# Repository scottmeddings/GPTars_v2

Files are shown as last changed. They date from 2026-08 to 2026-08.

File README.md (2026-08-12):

# GP-TARS V2 1000

Parametric CAD and software project for an approximately 1,000 mm tall autonomous walking TARS-style robot.

The downloaded GPTARS source geometry is reference-only. Primary loads must pass through the aluminium frame, steel shafts and bearings, aluminium actuator brackets, and aluminium chassis components. Production body panels are formed aluminium rather than printed plastic.

The current architecture uses a 6061-T6 aluminium load-bearing chassis and formed 5052-H32 aluminium bodywork. Steel is retained where mechanically necessary for shafts, bearings, motor internals, and selected fasteners.

## Compute baseline

Onboard compute is a vertically mounted **MINISFORUM AI X1 Pro-370** configured with:

- AMD Ryzen AI 9 HX370
- Radeon 890M integrated GPU
- XDNA 2 NPU
- **64 GB DDR5-5600 (2 × 32 GB)**
- **4 TB Lexar NQ780 PCIe 4.0 NVMe**
- **NVIDIA RTX 2000 Ada Generation 16 GB** through OCuLink

The RTX 2000 Ada is the primary CUDA accelerator for local AI inference, while the HX370 CPU, Radeon 890M and NPU remain available for secondary or fallback workloads.

## Software baseline

GP-TARS V2 is **local-first**. Core conversation, vision, memory, display, orchestration and robot-control functions should continue to work without Internet access.

Current software platform:

- **Ubuntu Server 24.04 LTS**
- Docker Engine
- NVIDIA Linux driver
- NVIDIA Container Toolkit
- CUDA-enabled AI containers
- ROS 2 Jazzy
- dedicated real-time safety/motion MCU over CAN/CAN-FD

The LLM operates only at the high-level behaviour layer. It does not directly command raw motor current, torque, PWM or unchecked joint positions. Deterministic motion limits, watchdogs, E-stop handling and safe-state transitions remain under the dedicated safety/motion controller.

See `docs/software_architecture.md` for the full container, ROS 2, memory, vision, speech, display and safety design.

## Power baseline

The canonical robot power architecture is **12.8 V nominal LiFePO4**, with the WattCycle 12.8 V 100 Ah Mini as the current battery baseline. The battery stays low and central.

The mini PC is intended to use a protected 12 V-to-USB-C-PD path through the rear USB4 PD input, subject to physical verification and sustained-load testing. The RTX 2000 Ada remains on its own protected power branch.

## Display / interaction module

The **display/TV is mounted at the top of GP-TARS** and acts as the robot's visual face. Camera and microphone hardware should be co-located with the display in a removable upper service cassette.

On the 1,000 mm robot, the current target interaction zone is approximately 850–950 mm above ground, with a possible 5–10 degree rearward screen tilt. The existing documented screen selection remains authoritative for final CAD cut-out and mounting dimensions.

Current vertical packaging intent:

```text
TOP
Display / face
Camera + microphones
Mini PC
RTX 2000 Ada + OCuLink dock
Power distribution / controllers
12.8 V battery
Walking structure
BOTTOM
```

## Motion development

Initial motion development begins with **two actuators** for bench and supported mechanism testing. Additional joints are added only after the first pair is validated for control, torque, thermal behaviour, current draw and mechanical integration.

Voice- or LLM-triggered movement remains disabled until physical E-stop, motor power isolation, watchdogs, joint limits, fault handling and restrained trajectory tests have passed.

## Current status

- Stage 1 source geometry inspection: complete
- Stage 2 scaled BREP import: blocked by missing `GP_TARS_V2_1000mm_scaled.brep`
- Stage 2 datum and joint proposal: documented, not frozen
- Stage 3 frame: earlier Fusion layout is concept-only and requires revision
- Stage 4 interference report: preliminary reservations documented
- 12.8 V power architecture: selected as design baseline
- upper display/face location: selected as design baseline
- 64 GB RAM + 4 TB NVMe compute configuration: selected as design baseline
- RTX 2000 Ada 16 GB: selected as external CUDA GPU baseline
- Ubuntu Server 24.04 + Docker + ROS 2 Jazzy: selected as software baseline
- local-first AI architecture: selected as software baseline

See `docs/original_geometry_analysis.md`, `docs/design_assumptions.md`, `docs/compute_hardware.md`, and `docs/software_architecture.md` before modifying the CAD or software stack.

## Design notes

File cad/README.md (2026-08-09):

# CAD automation

This directory will hold the parametric generators and exports for GP-TARS V2.

`parameters.py` is the current master configuration. The intended later entry point is `export.py`, which will generate STEP assemblies and STL panel outputs under `output/` without overwriting source GPTARS files.

The mechanical layout is not yet mature enough to generate production parts. Torque, mass, joint sweep, bearing life, shaft deflection, and stability calculations must precede actuator-bracket release.

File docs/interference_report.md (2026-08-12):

# Preliminary interference and reservation report

Status: preliminary envelope review only. A production interference report requires the missing scaled BREP, reconstructed joints, joint limits, and component sweep bodies.

> **Superseded by the 480 mm rebuild, 2026-08-10.** Everything below the Narrow-body section was written against the 958.7 mm scaled-source width and a horizontally mounted GPU. The clearances it reports no longer describe the model. It is retained as the record of how the wide layout failed.

## Narrow-body review, 480 mm

The body is now 480 mm wide as four 120 mm slabs, with a 240 mm central chassis, depth unchanged at 259.867 mm. Verified extent of the robot bodies, excluding the source reference envelope: **480.0 × 1000.0 × 259.9 mm**.

Equipment was repacked because the previous reservations were wider than the new chassis:

| Reservation | Was | Now | Reason |
|---|---|---|---|
| GPU | 300 × 130 × 60, flat | 130 × 300 × 60, vertical | The brief always specified a vertical card; the model had it flat, and 300 mm lateral no longer fits |
| Mini PC | 195 × 195 × 47.5, facing forward | 47.5 × 195 × 195, edge-on | Turning the board plane parallel to the side panels drops its lateral demand to 47.5 mm |
| Battery | 300 × 150 × 120 | 200 × 150 × 180 | Width traded for depth at approximately constant volume |

### Confirmed conflicts

An axis-aligned check over all 48 bodies returns 30 overlaps. Most are joint modules correctly occupying both parts they connect. Two are genuine defects:

| A | B | Overlap XYZ (mm) | Volume (mm³) | Disposition |
|---|---|---|---:|---|
| `FRAME_VERTICAL_1_0` | Mini PC service keep-out | 20 × 225 × 40 | 180,000 | **Real.** Move the rail outboard, split it around the PC, or reduce the service envelope |
| `FRAME_VERTICAL_1_1` | Mini PC service keep-out | 20 × 225 × 40 | 180,000 | **Real.** Same |
| `ACTUATOR_HIP_*` | Arm thigh and upper shells | 66 × 59 × 120 | 467,280 | Expected. A hip module must occupy both the chassis and the limb it drives |
| `ACTUATOR_KNEE_*` | Arm shin and thigh shells | 70 × 34 × 70 | 166,600 | Expected. Same reasoning at the knee |

The mini PC conflict is the packaging consequence of narrowing. At a 240 mm chassis the 225 mm service envelope cannot pass between 20 mm frame rails, so the rails, the envelope, or the service method must change before the frame is committed.

### Mass consequence

Skin area scales with perimeter. Narrowing takes the section perimeter from 2,437 mm to 1,480 mm, so the 1.2 mm aluminium skin falls from approximately 9.4 kg to **roughly 5.7 kg**. That is the largest single mass saving identified so far and materially improves the 12–25 kg target.

### Still not checked

Joint sweeps, cable bends, GPU dock and supply, connector protrusion, airflow, panel fasteners, service extraction paths, and clearance against a verified external BREP.

---

Latest concept model checked: Fusion document `GPTars_v4`, 90 bodies, exported to
`cad/output/GP_TARS_V2_R10.f3d`.

## R10 interference run

Run in Fusion over all 80 robot bodies, with the dock and the two transparent
reference envelopes excluded. Coincident faces were not counted.

- **47 interference pairs, all of them assembly contact**, and **zero
  non-assembly interference**. Assembly contact means a welded frame joint where
  a rail meets a depth member, a shaft through the carrier holding it, a keep-out
  against the part it reserves room for, a folded panel corner lap, or the dock
  contact plate against the panel it mounts to.
- The run caught three real clashes that reading the drawing would not have.
  Dropping the display to clear the camera brought the display module's lower
  edge onto the starboard power/CAN harness twice, and the camera's cassette
  plate landed on the front crossmember at Y=930–950. The harness now finishes
  at 615, still reaching the hip at 610.8, which is all it feeds; the plate now
  starts at 951, above the crossmember.

## Sensor provisions

Selected hardware, reserved at envelope size. Both reservations remain marked
for verification against the purchased units before any panel is cut.

| Provision | Envelope (mm) | Height above ground | Notes |
|---|---:|---:|---|
| Luxonis OAK-D Pro W USB | 160 x 45 x 45 | 945-990 | RGB and stereo depth in one module, covering both cameras the specification lists separately |
| Seeed Studio ReSpeaker XVF3800 USB 4-Mic Array | 90 x 35 x 20 | 978.8-998.8 | 4 channels under the top lid, ported up through it |
| Sensor cassette plate | 170 x 45 x 3 | 951-996 | Camera and microphones withdraw together |
| Time-of-flight, x2 | 26 x 26 x 18 | 317-343 | Step edges and near obstacles below the camera's field of view |
| LiDAR mount pad | 80 x 3 x 80 | 995.8-998.8 | Pad only. A 360 degree scanner stands proud of the lid and takes fitted height to 1042 mm |
| Foot contact, x2 | 24 cube | 54-78 | Inside each shoe's hollow |
| IMU | 40 x 25 x 40 | 290-315 | Unchanged |

Speakers are deliberately absent: the display module carries its own pair
(Two 32 mm, driven over HDMI audio), so reserving separate drivers would hold space for
hardware the robot already has.

### Why the cassette order changed

The upper front face between the hip break and the lid is **384.2 mm**. Camera
45 plus its 10 mm top margin, display module 328 and microphone 35 need
**418 mm**: 33.8 mm over, and still 23.8 mm over with every margin zeroed. The
microphones cannot stay on the front face, so they mount under the lid.

That resolved, the rest follows arithmetically. The camera occupies
945-990 mm, so the 328 mm display module must finish by 944, which sets
`DISPLAY_ORIGIN_Y` to 625. The aperture doubler's flange drops from 18 mm to
10 mm so it clears the hip break at 613.8 mm. Clearances are small:
1.41 mm under the display module and 1 mm between module and camera.

## Reserved equipment envelopes

| Reservation | Envelope (mm) | Preferred region | Current result |
|---|---:|---|---|
| Battery | 300 × 150 × 120 | Lowest central bay | Plausible within 532 mm scaled chassis width; joint sweep not checked |
| MINISFORUM AI X1 Pro body | 195 × 195 × 47.5 | Vertical above battery | Selected hardware; exact body now modelled |
| Mini-PC service keep-out | 225 × 225 × 100 | Around selected PC | Includes initial airflow, cable, isolator and removal allowance |
| Required external NVIDIA GPU | 300 × 130 × 60 provisional card-only envelope | Vertical, central, dedicated access | LLM accelerator required; exact card, PSU, OCuLink adapter, cable bend and airflow not checked |
| Main actuator | Ø120 × 100 maximum placeholder | At proposed main joint modules | May conflict with shallow 259.9 mm body depth after brackets/bearings |
| Secondary actuator | Ø70 × 70 placeholder | Linkage zones | Not yet placed |
| Main battery disconnect / fuse / contactor | TBD | Low service-access side | Reserved conceptually only |

## Continuity audit against every earlier model

Every archive in the repository's history was reopened and its bodies compared
by name against the current model. This is the check that matters most here,
because a previous model was lost once already.

| Archive | Bodies | Extent (mm) | Missing from the current model |
|---|---:|---|---|
| CONCEPT_V0 | 29 | 793.5 × 920 × 224.9 | Old frame naming; upper and secondary actuator reservations |
| ALUMINIUM_CONCEPT_V1 | 29 | 793.5 × 920 × 224.9 | As above |
| ALUMINIUM_COMPUTE_V2 | 30 | 793.5 × 920 × 224.9 | As above |
| NARROW480_CAGE_V1 | 18 | 958.7 × 1000 × 259.9 | Old frame naming only |
| R03 | 67 | 480 × 1000 × 259.9 | 24:1 reduction bodies |
| R04 | 67 | 480 × 1000 × 259.9 | 24:1 reduction bodies |
| R05 | 80 | 480 × 1000 × 259.9 | 24:1 reduction bodies |
| **R06** | 80 | 480 × 1000 × 259.9 | **nothing** |
| **R07** | 82 | 480 × 1000 × 259.9 | **nothing** |
| **R08** | 82 | 480 × 1000 × 259.9 | **nothing** |
| **R09** | 82 | 480 × 1000 × 259.9 | **nothing** |

The current model is a strict superset of R06 through R09: every body name in
those archives exists in it, plus the eight new sensor bodies.

Everything the earlier archives appear to be missing is a rename or a recorded
decision, not a loss:

- **24:1 reductions** became `REDUCTION_HIP_*_32TO1`. The ratio was raised
  deliberately to clear the hip torque requirement.
- **`FRAME_VERTICAL_*`, `FRAME_CROSS_*`, `FRAME_DEPTH_*`** and the
  `Frame_Vert_*` set became `RAIL_*`, `CROSS_*` and `DEPTH_*`. The current frame
  carries 28 members against the old 22, and models them as hollow section
  rather than solid bar.
- **`MINI_PC_KEEP_OUT`** became `MINISFORUM_AI_X1_PRO_SERVICE_KEEP_OUT` once the
  machine was selected.
- **`ACTUATOR_MAIN_LOWER_*_KEEP_OUT`** became `ACTUATOR_HIP_*_AK45_10`.
- **`ACTUATOR_MAIN_UPPER_*` and `ACTUATOR_SECONDARY_*`** have no equivalent, by
  design. See risk 2 above.

The three 793.5 × 920 × 224.9 concepts predate both the 480 mm narrowing and the
1,000 mm envelope being applied to the bodies themselves, so their geometry is
superseded wholesale rather than carried forward.

## Early risks

1. **Actuator-depth risk:** two 100 mm-long actuator modules plus dual-bearing support, brackets, wiring bends, and shell clearance consume much of the approximately 259.9 mm depth.
2. **Upper reference axes are not articulated in this build.** The source geometry carries axes at Y=786.1, 838.0 and 889.9 mm and they remain in `cad/parameters.py` as reference. This build does not articulate them: `UPPER_CHASSIS_ASSUMED_RIGID = True`, the gait is a compass walker with rigid limbs and no knees, and the display module now occupies Y=616–944, straight through that band. The earlier concept models reserved actuator volume at those axes; this one deliberately does not. The GPU conflict this risk originally described no longer exists.
3. **Lower-joint/battery conflict:** the lower main axis is near Y=611 mm, leaving useful low volume, but rotating links may sweep into a tall battery compartment.
4. **Frame/shell clearance:** the concept extrusion frame was created from a simple chassis box, not the actual scaled shell surfaces. Clearance is unverified.
5. **Wiring bend radius:** CAN/power cables crossing rotating X-axis joints require loops, guides, or rotary routing. No sweep reservation exists yet.
6. **Cooling path:** a vertical GPU helps bottom-to-top airflow, but structural crossmembers must not block intake/exhaust areas.
7. **Service extraction:** GPU and PC trays must slide out without crossing main shaft or actuator removal paths.
8. **COG uncertainty:** no trustworthy component masses are assigned; stability conclusions cannot yet be drawn.
9. **Aluminium skin mass:** a complete 1.2 mm rectangular-envelope skin would be approximately 9.4 kg before formed returns and hardware. Actual panel geometry and openings require a controlled mass budget.

## Concept V0 static-envelope results

The check included 29 frame and keep-out solids. All checked bodies are contained within the rectangular 958.718 × 1000 × 259.867 mm external reference envelope. This is not equivalent to clearance from the detailed TARS shell, which remains unavailable as the named scaled BREP.

No battery/compute/GPU keep-out bodies overlap one another. Four frame-to-main-actuator conflicts were found:

| Frame member | Actuator keep-out | Overlap XYZ (mm) | Volume (mm³) | Disposition |
|---|---|---:|---:|---|
| `FRAME_VERTICAL_0_1` | Lower starboard main | 20.020 × 120.020 × 5.024 | 12,071.7 | Redesign rail/carrier interface |
| `FRAME_VERTICAL_1_1` | Lower port main | 20.020 × 120.020 × 5.024 | 12,071.7 | Redesign rail/carrier interface |
| `FRAME_VERTICAL_0_0` | Upper starboard main | 5.979 × 120.020 × 14.997 | 10,761.8 | Move/split rail or integrate bearing carrier |
| `FRAME_VERTICAL_1_0` | Upper port main | 5.979 × 120.020 × 14.997 | 10,761.8 | Move/split rail or integrate bearing carrier |

These conflicts confirm that uninterrupted vertical extrusion rails are not a final solution at the main joints. The preferred next study is a fabricated/CNC transverse joint bulkhead that carries the dual bearings and actuator bracket, with 20×40 rails terminating into that bulkhead.

## Compute V2 static-envelope results

The selected MINISFORUM AI X1 Pro is represented by an exact 195 × 195 × 47.5 mm body and a provisional 225 × 225 × 100 mm service keep-out. It is mounted vertically in the lower central bay, above the battery reservation.

- No PC-body or PC-service-envelope overlap was found with a structural frame member.
- The service envelope finishes at Y=390 mm and the GPU keep-out starts at Y=420 mm, leaving 30 mm between reservations.
- The battery keep-out finishes at Y=150 mm and the PC service envelope starts at Y=165 mm, leaving 15 mm between reservations.
- The exact PC body has 45 mm to the GPU reservation and 30 mm to the battery reservation.
- Intersections with `EXTERNAL_REFERENCE_ENVELOPE` and `CENTRAL_CHASSIS_REFERENCE` are intentional because those bodies are transparent reference volumes, not physical parts.

These are static axis-aligned clearances. Connector protrusion, USB4/OCuLink cable bend radii, ventilation flow, tray fasteners, vibration isolators, and removal motion still require detailed modelling.

## Required Stage 4 checks

- Import the verified 1,000 mm external BREP as a non-structural reference.
- Create joint sweep bodies for every proposed moving module.
- Check frame members against static shell clearance and full sweep.
- Check Ø120×100 main-actuator placeholders against shell, bearings, and service-tool access.
- Check battery tray against lower-link sweep plus 10–25 mm ground-clearance requirements.
- Check GPU, PC, and wiring reservations against frame and actuator removal paths.
- Add at least 10 mm general wiring space, larger at high-current bends and moving joints.
- Produce a Fusion interference table with component pairs, overlap volume, and disposition.

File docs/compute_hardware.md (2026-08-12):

# Compute hardware

## Selected mini PC

Model: **MINISFORUM AI X1 Pro-370 barebone**

| Item | Value |
|---|---|
| Processor | AMD Ryzen AI 9 HX370, 12 cores / 24 threads |
| Integrated GPU | AMD Radeon 890M |
| NPU / total AI performance | Up to 80 TOPS total |
| Memory | **64 GB DDR5-5600, 2 × 32 GB SO-DIMM** |
| Primary storage | **4 TB Lexar NQ780 M.2 2280 PCIe 4.0 NVMe** |
| External GPU link | OCuLink PCIe 4.0 x4 |
| Networking | Two 2.5 GbE ports, Wi-Fi 7, Bluetooth 5.4 |

## Compute configuration baseline

- **MINISFORUM AI X1 Pro-370 / Ryzen AI 9 HX370**
- **64 GB DDR5-5600**
- **4 TB Lexar NQ780 PCIe 4.0 NVMe**
- **NVIDIA RTX 2000 Ada 16 GB through OCuLink — planned later-phase accelerator, not required for initial operation**

Phase 1 is explicitly designed to operate without the RTX 2000 Ada. The HX370 runs the local LLM, speech, memory, orchestration and ROS services, while the selected vision camera performs depth and useful neural inference onboard.

## Selected vision and audio sensors

The GP-TARS V2 perception baseline is now locked as:

- **Vision / depth camera: Luxonis OAK-D Pro W — USB version**
- **Connection: USB 3 to the MINISFORUM**
- **Microphone: ReSpeaker USB 4 Mic Array**
- **Location: removable upper display / face cassette**
- **Software ownership: `tars-vision` and `tars-stt` containers**

The **W (wide-FOV) USB model** is intentionally selected instead of the standard OAK-D Pro and instead of the PoE version. The short internal cable run in GP-TARS makes USB simpler than PoE, while the wide field of view is valuable for a mobile robot that should perceive people and obstacles without constantly rotating its body.

### Luxonis OAK-D Pro W USB

The OAK-D Pro W is the primary GP-TARS perception camera. It combines RGB vision, wide-angle stereo depth, onboard AI processing, active IR depth assistance and an integrated IMU in a compact camera module.

The onboard vision processor is particularly important during Phase 1 because GP-TARS will initially operate **without the RTX 2000 Ada installed**. Basic continuous perception should therefore run on the OAK where practical rather than consuming HX370 resources needed by the local LLM and speech stack.

Target uses:

- person detection and tracking
- face/person recognition where explicitly configured
- stereo distance estimation
- obstacle and free-space perception
- object detection and tracking
- gesture and pose detection
- locating/interacting with a person in the room
- navigation and mapping observations
- low-light / IR-assisted depth perception
- structured spatial observations for the TARS agent

The camera should publish structured observations rather than forcing the LLM to inspect continuous raw video.

Example:

```text
PERSON_DETECTED
track_id: 14
position: left
range_m: 1.82
confidence: 0.96
```

### Phase 1 vision architecture

```text
OAK-D PRO W USB
      |
      +-- RGB
      +-- wide stereo depth
      +-- onboard neural inference
      +-- tracking / spatial data
      |
      +-- USB 3
             |
             v
       tars-vision
             |
             +-- structured observations
             +-- ROS 2 / application events
             |
             v
       TARS CORE / BEHAVIOUR

HX370
  +-- Local LLM
  +-- STT / TTS
  +-- Memory
  +-- TARS agent
  +-- ROS 2
  +-- Robot services

RTX 2000 ADA
  +-- ADD LATER for heavier CUDA vision/LLM workloads
```

When the RTX 2000 Ada is added, heavier face, pose, scene-understanding or multimodal models can move to CUDA while the OAK continues providing depth, tracking and efficient always-on perception.

### Camera mounting

- Mount directly above or immediately adjacent to the upper display.
- Preserve the full wide field of view; no bezel or decorative panel may obscure the stereo cameras or IR system.
- Prefer a fixed-focus configuration for vibration robustness where the selected SKU permits.
- Use a short, high-quality USB 3 cable with strain relief.
- If the host USB power budget proves insufficient with IR illumination enabled, provide the camera with the manufacturer-supported external-power/Y-cable arrangement from the regulated accessory supply.
- Final mounting holes and connector cut-outs must be based on the purchased camera or authoritative mechanical drawing.
- Provide at least 10 mm service/cable clearance around connector faces until final CAD is verified.

**Now in the CAD, and the stack had to change to fit.** Camera, microphones,
their cassette plate, a ToF pair, a LiDAR pad and a contact sensor in each shoe
are modelled in `10_SENSORS` as reserved volumes.

The cassette as originally ordered — camera above the display, microphones below
it, all on the upper front face — does not fit. The camera's 45 mm reservation
plus its 10 mm top margin, the 328 mm display module and the 35 mm microphone
reservation need 418 mm. The upper front face between the hip break and the lid
is 384.2 mm. That is 33.8 mm over, and still 23.8 mm over with every margin set
to zero.

The microphones therefore mount under the top lid, behind the camera, ported up
through it. That fits, and it is the better position anyway: further from the
display's heat, and a far-field array on the lid beats one on a front panel that
drums. The remaining stack sets the display: the camera occupies 945–990 mm, so
the display module has to finish by 944, which puts `DISPLAY_ORIGIN_Y` at 625.
The aperture doubler's flange drops from 18 mm to 10 mm so it clears the hip
break at 613.8 mm.

Both reservations are still marked for verification against purchased hardware
before any panel is cut. See `docs/interference_report.md` for the envelope
table and the interference run.

The display module must not become a primary structural load path. Walking and impact loads pass through the internal aluminium chassis.

### ReSpeaker USB 4 Mic Array

The ReSpeaker USB 4 Mic Array remains the preferred initial far-field microphone system.

Required capabilities include four-microphone capture, far-field pickup, beamforming, direction-of-arrival information where available, voice activity detection, noise suppression, acoustic echo cancellation where supported, and standard USB audio operation under Ubuntu Linux.

The microphone array feeds `tars-stt` for wake-word detection, speech capture and local speech-to-text. Direction information can be combined with OAK vision tracking so TARS can associate a voice with a visible person.

### Upper sensor cassette

```text
TOP OF TARS

+--------------------------------+
|       OAK-D PRO W USB           |
|    wide RGB + stereo depth      |
|                                |
|          DISPLAY               |
|      TARS face / status        |
|                                |
|    RESPEAKER 4-MIC ARRAY       |
+--------------------------------+
```

The complete camera/display/microphone assembly should be removable as one service cassette. The microphone array should use compliant/vibration isolation and be kept away from fan exhaust, speakers and actuator vibration paths.

Audio must be validated with fans, speakers and actuators running. The final speech pipeline should support acoustic echo cancellation and barge-in so a person can naturally interrupt TARS while it is speaking.

## Storage allocation

- **Primary M.2:** 4 TB Lexar NQ780 — Ubuntu, Docker, active AI models, databases and applications
- **Second M.2:** reserved for future model/data expansion
- **Third M.2:** reserved for telemetry, logs, recordings, cache or backup workloads

## CAD / vertical layout

```text
TOP OF ROBOT

OAK-D PRO W USB
DISPLAY / FACE
RESPEAKER MICROPHONE ARRAY

MINISFORUM HX370
RTX 2000 ADA + OCuLink DOCK (LATER PHASE)

POWER DISTRIBUTION / CONTROLLERS

12.8 V LiFePO4 BATTERY

LOWER BODY / WALKING STRUCTURE
```

The battery remains low and central. Compute stays near the middle of the body. Display and perception sensors remain high for interaction and field of view.

## Selected robot power architecture

GP-TARS V2 uses a **12.8 V nominal LiFePO4 main battery bus**. The preferred current battery is the WattCycle **12.8 V 100 Ah Mini LiFePO4**, approximately **1,280 Wh** installed energy.

Power domains remain separated:

```text
12.8 V LiFePO4 MAIN BUS
      |
      +-- MOTION CONTACTOR / E-STOP --> motion conversion / actuators
      +-- COMPUTE FUSE --> mini PC power conversion
      +-- FUTURE GPU FUSE --> RTX 2000 Ada / OCuLink dock
      +-- AUX FUSE --> regulated accessory rail --> display/audio/camera/fans
      +-- SAFETY SUPPLY --> safety MCU / contactor supervision
```

The physical E-stop removes actuator power immediately while leaving the safety controller and, where practical, compute/perception powered.

## Thermal and integration requirements

- Do not block mini-PC inlet/exhaust.
- Preserve clear airflow for the future RTX 2000 Ada.
- Cool the 4 TB NVMe for sustained Docker/model/database workloads.
- Keep display heat away from camera and microphone electronics where practical.
- Isolate microphone mounting from structure-borne walking vibration.
- Provide strain relief for OAK USB and ReSpeaker USB cables.
- Do not make the upper sensor cassette a primary structural load path.

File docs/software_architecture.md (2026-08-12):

# GP-TARS V2 software architecture

Status: software baseline, revision Software V3.

## Core decision

GP-TARS V2 is a **local-first autonomous robot**. Core conversation, perception, memory, display, orchestration and safety functions must continue to operate without Internet access.

Use TARS-AI V3 as a reusable source for character/persona, speech, memory, vision and user-interface concepts where practical. Replace its hobby-servo motion layer with a ROS 2 control stack and a separate real-time safety/motion controller.

The operating principle is:

> TARS-AI supplies the character. ROS 2 supplies the robot. A dedicated MCU supplies deterministic motion and safety.

The LLM is never a motor controller.

## Host platform

Primary compute baseline:

- **MINISFORUM AI X1 Pro-370**
- AMD Ryzen AI 9 HX370
- Radeon 890M integrated GPU
- XDNA 2 NPU
- **64 GB DDR5-5600, 2 × 32 GB**
- **4 TB Lexar NQ780 PCIe 4.0 NVMe**
- **NVIDIA RTX 2000 Ada Generation 16 GB** via OCuLink

Operating system baseline:

- **Ubuntu Server 24.04 LTS**
- Docker Engine
- NVIDIA Linux driver
- NVIDIA Container Toolkit
- CUDA runtime for GPU-enabled containers
- ROS 2 Jazzy

The RTX 2000 Ada is the primary CUDA accelerator for local LLM inference and other heavy AI workloads. The HX370 CPU, Radeon 890M and XDNA 2 NPU remain available for secondary, low-power or fallback workloads where supported.

## Build-readiness rule

This architecture document defines **what GP-TARS is and how the software components fit together**. It is intentionally paired with `docs/ubuntu_server_build.md`, which defines **how to reproduce the server from a blank Ubuntu installation**.

A production-ready build must not depend on undocumented manual knowledge. The Ubuntu build document must eventually contain exact package versions or supported version ranges, repository keys, NVIDIA/CUDA validation, Docker configuration, filesystem layout, service accounts, Compose files, environment variables, persistent volumes, network ports, firewall rules, boot ordering, health checks, backup/restore, update procedure and acceptance tests.

## Layered system

1. **Independent safety:** hardwired E-stop loop, motor contactor, power isolation and hard limits.
2. **Real-time motion:** dedicated MCU connected by CAN/CAN-FD; encoder monitoring, actuator commands, brakes, joint limits, watchdog and safe stop.
3. **Robot control:** ROS 2 Jazzy on Ubuntu 24.04 LTS; URDF/Xacro model, ros2_control hardware interface, trajectories, state estimation and diagnostics.
4. **Behaviour supervisor:** validates high-level intent against mode, robot state, balance, limits, active faults and operator permission.
5. **TARS experience layer:** personality, teaching mode, wake word, STT, TTS, memory/RAG, vision, display, dashboard and skills.

The MINISFORUM AI X1 Pro runs the non-real-time layers. It must not perform motor commutation or be the only path to a safe shutdown.

## Container architecture

GP-TARS software should be split into small services rather than one monolithic container.

| Service | Responsibility |
|---|---|
| `tars-core` | Main orchestrator, state machine and behaviour coordination |
| `tars-llm` | Local LLM inference |
| `tars-personality` | TARS persona, user-specific tone, teaching adaptation and response policy |
| `tars-memory` | User profiles, semantic memory, episodic memory and RAG |
| `tars-stt` | Wake word, voice activity detection and speech-to-text |
| `tars-tts` | Local text-to-speech |
| `tars-vision` | Camera ingestion, person/object detection and tracking |
| `tars-display` | Top display/face UI, states and animation |
| `tars-ros` | ROS 2 bridge and robot-state integration |
| `tars-motion` | Gait, kinematics, pose and trajectory requests |
| `tars-can` | Controlled software interface to the safety/motion MCU |
| `tars-api` | REST/WebSocket management API |
| `tars-web` | Local browser management and diagnostics UI |
| `tars-telemetry` | Logs, metrics, health and diagnostics |

Only containers that require CUDA should receive access to the RTX 2000 Ada. GPU access is not granted to every container by default.

## Personality architecture

GP-TARS should feel recognisably inspired by **TARS from Interstellar** without relying on copied film dialogue. The personality is a behavioural profile rather than a collection of quotes.

Core traits:

- highly competent and mission-focused
- calm under pressure
- concise and direct
- dry, deadpan humour
- occasional sarcasm without becoming insulting
- loyal and protective toward known users
- willing to state uncertainty plainly
- practical rather than sentimental
- confident without pretending to know things it does not know
- capable of switching instantly from humour to serious safety behaviour

The film character's well-known configurable-personality concept should be retained as explicit settings. GP-TARS should expose at least:

- **Humour** — 0 to 100
- **Honesty/directness** — 0 to 100
- **Verbosity** — low / medium / high
- **Teaching mode** — off / opportunistic / active
- **Age adaptation** — automatic from authorised profile, or manually selected
- **Formality** — casual / neutral / formal

These values influence phrasing and interaction style only. They never weaken mechanical safety, privacy, content controls or permissions.

### Default TARS-style profile

Initial baseline:

```text
Humour: 75%
Honesty/directness: 90%
Verbosity: concise
Formality: neutral-casual
Teaching mode: opportunistic
```

Humour should normally be short, dry and situational. It must not interfere with warnings, emergencies, instructions or teaching clarity.

## Person-aware interaction

When identity recognition is enabled and the person is authorised, `tars-personality` retrieves that person's interaction profile from `tars-memory`.

The profile may include:

- preferred name
- age or age band
- relationship/role
- preferred communication style
- learning level and known competencies
- subjects being learned
- interests
- accessibility requirements
- permissions
- teaching preferences
- humour tolerance

Identity changes **interaction**, not physical safety rules.

If identity confidence is low, GP-TARS must fall back to a neutral general-audience profile rather than guessing a person's age or permissions.

## Teaching and learning mode

Teaching is a first-class GP-TARS capability rather than a generic LLM side effect.

The goal is for TARS to notice reasonable learning opportunities and teach at the right level without becoming intrusive.

Examples:

- a child struggles with multiplication, so TARS offers a short guided times-table exercise
- a learner misspells a word repeatedly, so TARS explains the spelling pattern and checks understanding
- a teenager asks a science question, so TARS answers at an appropriate conceptual level and can offer a quick challenge question
- an adult asks about electronics, CAD or programming, so TARS can move directly into a more technical explanation

### Age-aware teaching bands

These are pedagogical defaults, not assumptions about intelligence.

| Profile | Teaching behaviour |
|---|---|
| Young child | Short sentences, concrete examples, one concept at a time, encouragement, frequent comprehension checks |
| Older child | Step-by-step explanation, simple analogies, guided practice, gradually reduced hints |
| Teen | More technical vocabulary, reasoning and problem solving, challenge questions, explain why rather than only how |
| Adult | Concise by default, full technical depth on request, fewer unnecessary comprehension checks |
| Unknown user | Neutral general-audience style until identity/profile is resolved |

### Teaching loop

```text
Observe question or difficulty
        |
        v
Check user profile + age band + learning history
        |
        v
Estimate current level
        |
        v
Explain one useful concept
        |
        v
Ask / observe a small check for understanding
        |
        +-- understood --> continue or return to normal interaction
        |
        +-- not understood --> re-explain using another method
        |
        v
Store useful learning progress with appropriate privacy controls
```

Teaching should favour guided reasoning over simply giving answers when the user is clearly trying to learn. However, TARS should still answer direct factual questions normally unless a lesson is useful and appropriate.

### Opportunistic teaching

When `Teaching mode = opportunistic`, TARS may occasionally offer help when it detects repeated difficulty, but it should not constantly quiz people. Offers should be brief and easy to decline.

When `Teaching mode = active`, an authorised parent, guardian, teacher or adult user may configure learning goals, subjects, practice frequency and progress tracking.

## Child interaction safeguards

Age-aware personality must be paired with stricter privacy and permission handling for children.

- child profiles must not inherit adult permissions
- private memories belonging to other users must not be disclosed
- purchasing, account changes, external communications and other consequential actions require appropriate authorisation
- location sharing and personal data exposure must be restricted
- teaching history should store only what is useful and permitted
- recognised-child behaviour must never modify robot motion safety thresholds
- uncertain identity falls back to a safe neutral profile

Parental/family override and configuration should be supported through the management interface.

## Community software reuse

| Subsystem | Decision | Treatment |
|---|---|---|
| Character/persona system | Reuse/adapt | Preserve recognisable TARS character and configurable humour/directness |
| Wake word, STT and barge-in | Reuse/adapt | Retain a modular local speech pipeline |
| TTS | Reuse/adapt | Local, low-latency speech |
| Memory/RAG and message routing | Reuse/adapt | Place behind stable service boundaries |
| Vision and web dashboard | Adapt | Run heavy work on the mini PC / RTX GPU |
| Movement skill registry | Adapt | Emit restricted high-level ROS actions only |
| PCA9685 hobby-servo control | Replace | Not suitable for full-scale walking loads |
| Threaded direct movement calls | Replace | Use supervised, cancellable, monitored ROS actions |

Primary references:

- TARS-AI V3: https://github.com/TARS-AI-Community/TARS-AI
- Original GPTARS Interstellar project: https://github.com/poboisvert/GPTARS_Interstellar
- ROS 2 Jazzy
- ros2_control
- llama.cpp or another CUDA-capable local inference runtime

## LLM command boundary

The LLM may request only named, high-level actions, for example:

```text
perform_gesture("wave_right")
walk_relative(distance=0.30, speed=0.05)
turn_relative(angle_degrees=15)
stop_motion()
return_to_neutral()
approach_person(person_id="known-user")
display_expression("thinking")
start_lesson(subject="multiplication", learner_id="known-user")
```

The LLM must never receive an interface for raw PWM, motor current, direct torque, unchecked joint angles, disabled limits or safety bypass.

The behaviour supervisor approves every motion request. ROS actions provide execution feedback and cancellation. The real-time MCU independently rejects stale, malformed or out-of-limit commands.

## ROS communication model

Use ROS 2 for robotics data and control:

- **Topics:** joint state, IMU, camera/sensor state, temperatures, battery, faults and diagnostics.
- **Services:** configuration reads, maintenance-mode transitions and approved fault resets.
- **Actions:** cancellable walking, turning, homing, recovery and gesture sequences with progress feedback.
- **Hardwired:** E-stop, motor contactor and final power removal remain independent of ROS and the LLM.

## Application event bus

Use NATS or MQTT for application-level events that do not belong in the real-time robotics layer, for example:

```text
person.detected
person.recognised
speech.started
speech.completed
battery.low
robot.wake
robot.sleep
user.profile.changed
lesson.started
lesson.completed
learning.progress.updated
fault.reported
```

The exact choice between NATS and MQTT remains open.

## Management interfaces

Use REST and WebSocket APIs for browser management UI, configuration, health and diagnostics, telemetry dashboards, local development tools and safe operator commands.

The management UI should also provide authorised controls for personality values, user profiles, teaching goals, child permissions and learning-history review.

## Memory architecture

GP-TARS memory should be divided into distinct scopes:

- **Working memory** — current conversation and immediate environment
- **Session memory** — events since boot/session start
- **Personal memory** — known people, preferences and relationships
- **Semantic memory** — manuals, project documents and general facts
- **Episodic memory** — notable previous interactions and experiences
- **Learning memory** — learner level, recent exercises, recurring difficulties and progress
- **Robot memory** — faults, battery history, actuator temperatures, maintenance and calibration history

Current database baseline:

- PostgreSQL
- pgvector

Memory retrieval must be identity- and policy-aware so the robot does not disclose one user's private information to another person.

## Vision and identity

The vision service is responsible for camera capture, person detection, face/person recognition where enabled, object detection, tracking and spatial context.

Recognised users may receive different interaction styles, teaching levels or profiles, but **mechanical safety rules never change based on identity**.

The primary interaction camera should be physically co-located with the top display/face module.

## Speech architecture

```text
microphone array
      |
      v
wake word / VAD
      |
      v
speech-to-text
      |
      v
TARS agent + personality profile
      |
      v
text-to-speech
      |
      v
speakers + display animation
```

Speech recognition and synthesis should operate locally where practical.

## Display architecture

The top-mounted display is controlled by `tars-display`.

Responsibilities include TARS face/expression rendering, listening/thinking/speaking states, teaching visuals, warnings and fault status, boot/self-test state, battery/connectivity indicators and local setup/status UI.

The display service should auto-start into kiosk/full-screen mode without requiring a full Ubuntu desktop environment.

## Motion and actuator architecture

Initial mechanical/software development starts with **two actuators** and expands only after the first pair is validated.

Motion services are responsible for requested pose, forward/inverse kinematics, gait generation, joint trajectory planning, synchronisation and balance logic.

The safety MCU remains authoritative for motor enable, hard joint limits, current/torque limits, temperature limits, watchdog timeout, E-stop handling, communications loss and safe shutdown.

## Safety MCU

A dedicated deterministic MCU such as STM32 or Teensy-class hardware provides the final safety/control boundary.

The host computer sends a continuous heartbeat. Loss of heartbeat, invalid command sequencing, over-current, thermal faults or E-stop activation forces the motion system to a defined safe state without depending on Docker, ROS 2 or the LLM.

## Proposed repository structure

```text
software/
├── compose/
│   └── docker-compose.yml
├── ros2_ws/src/
│   ├── gptars_description/
│   ├── gptars_interfaces/
│   ├── gptars_hardware/
│   ├── gptars_control/
│   ├── gptars_safety/
│   ├── gptars_behaviors/
│   ├── gptars_state/
│   └── tars_ai_bridge/
├── firmware/
│   └── motion_controller/
├── ai/
│   ├── llm/
│   ├── personality/
│   ├── memory/
│   ├── teaching/
│   ├── speech/
│   └── vision/
├── display/
├── dashboard/
├── config/
├── simulation/
└── tests/
```

## Startup sequence

1. Safety MCU boots with motion disabled.
2. Battery and contactor state are checked.
3. Ubuntu Server boots.
4. Docker services start.
5. Core health services initialise.
6. Cameras, microphones and display initialise.
7. Local LLM loads.
8. Personality, memory and teaching services initialise.
9. ROS 2 and robot-state services start.
10. Computer-to-MCU heartbeat is established.
11. GP-TARS performs a self-test.
12. Display shows ready state.
13. Motor enable becomes available only if safety checks pass.

## Failure behaviour

- **LLM crash:** robot remains mechanically safe; AI service may restart independently.
- **Personality/teaching crash:** interaction falls back to neutral general-audience mode.
- **GPU failure:** robot can fall back to CPU/iGPU/NPU-supported functions where practical.
- **Container failure:** supervisor restarts the failed service; MCU safety remains independent.
- **Wi-Fi/Internet loss:** local robot operation continues.
- **ROS/motion heartbeat loss:** MCU disables motion.
- **E-stop:** actuator power is removed while safety/compute power remains available where practical for logging and status reporting.

## Storage use

The 4 TB primary NVMe stores Ubuntu Server, Docker images and volumes, local AI models, speech models, vision models, PostgreSQL/pgvector data, application code, learning profiles, telemetry and active logs.

Additional M.2 slots remain available for model libraries, recordings, long-term telemetry or backup data.

## Development sequence

1. Ubuntu Server 24.04 + Docker + NVIDIA driver + CUDA validation.
2. Local LLM container.
3. Wake word, speech-to-text and text-to-speech.
4. TARS personality/orchestration layer.
5. Memory, identity and user profiles.
6. Age-aware teaching service.
7. Top display/face service.
8. Vision and person recognition.
9. ROS 2 integration and URDF/Xacro simulation.
10. Safety MCU and CAN protocol.
11. First two actuator bench tests.
12. Supported two-actuator body-motion tests.
13. Additional joints and gait development.
14. Autonomous navigation and higher-level behaviours.

## Initial acceptance milestone

Before locomotion work, GP-TARS should be able to boot autonomously, show its face/status on the top display, listen for a wake word, transcribe speech locally, run the local LLM through CUDA on the RTX 2000 Ada, recognise an authorised user, load the correct personality/age profile, retrieve relevant memory, teach a short age-appropriate lesson, generate a spoken response, animate the display while speaking, operate without Internet access and expose health/diagnostics through the local web interface.

## Safety release gate

Voice- or LLM-triggered movement remains disabled until the physical E-stop, contactor removal, communications watchdog, joint limits, fault handling and restrained trajectory tests have all passed.

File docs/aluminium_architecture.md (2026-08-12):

# Hybrid mechanical architecture

## Decision

GP-TARS V2 will use aluminium for the load-bearing chassis, actuator carriers and equipment trays, with steel at highly loaded shafts and bearing elements. Removable formed 5052-H32 aluminium panels will form the recognisable external TARS body.

This supersedes the printed-polymer bodywork called for in the original brief; `docs/project_specification.md` carries the same revision note.

The external shell is cosmetic and must never become part of the walking load path. Safety-critical material exceptions include:

- steel main and secondary shafts;
- steel bearing races and rolling elements;
- motor, gearbox, encoder, wiring, insulation, seals, tyres/contact pads, and electronic materials;
- stainless or high-strength steel fasteners where joint preload, wear, or repeated service requires them.

Using aluminium shafts, bearing races, or highly loaded aluminium fasteners is rejected as the baseline because of wear, galling, fatigue, and stiffness limits.

## Material schedule

| System | Material | Initial thickness/profile | Manufacturing intent |
|---|---|---|---|
| Primary frame | 6061-T6 aluminium | 20×40 at primary paths | Extrusion or rectangular tube terminating at joint bulkheads |
| Light crossmembers | 6061-T6 aluminium | 20×20 | Equipment support and anti-racking members |
| Main joint bulkheads | 6061-T6 plate | 8 mm starting point | CNC-machined; thickness requires FEA and bearing-load checks |
| Actuator brackets | 6061-T6 plate | 8 mm starting point | CNC/fabricated; locally gusseted |
| Exterior panels | 5052-H32 aluminium sheet | 1.2 mm nominal, 1.0–1.6 mm range | Formed and folded removable cosmetic shell with replaceable mounting plates |
| Battery tray | 5052-H32 sheet | 3 mm | Folded metal tray with bolted retainers and strap |
| Compute/GPU trays | 5052-H32 sheet | 2 mm | Folded removable trays with vibration isolators |
| Access-panel doublers | 5052-H32 or 6061-T6 | 2 mm | Riveted/bolted behind frequently serviced edges |

5052-H32 remains suitable for folded internal trays and is now also the exterior panel material; it forms well and resists corrosion, but it is not heat-treatable and must not be substituted for 6061-T6 anywhere in the load path. 6061-T6 is preferred for machined plates, carriers and stiff structural members. Final panel gauge and forming process will be confirmed after stiffness, dent-resistance and fastener-pull-through testing on representative coupons.

## Panel design rules

- Do not scale the source shell thickness.
- Divide the shell into independently removable service panels.
- Use folded returns, swaged beads and local doublers to control flex without turning the shell into a structural member.
- Use replaceable mounting plates or isolated inserts at hinges, latches, handles and concentrated fasteners.
- Isolate dissimilar metals from aluminium to limit galvanic corrosion, and isolate panel fixings to limit fretting against the chassis.
- Use captive nuts, rivnuts, nut plates or replaceable interfaces attached to the structural chassis.
- Deburr and radius every formed edge; a 1.2 mm sheet edge is a laceration hazard on a machine people stand next to.
- Make compute, GPU, battery, motor controller, and actuator panels independently removable.
- Deburr and radius all wiring penetrations; add grommets or edge protection.

## Mass warning

This is the most serious consequence of the aluminium bodywork decision. A complete 1.2 mm skin over the rectangular envelope is approximately **9.4 kg** before formed returns, doublers and hardware, against a **12–25 kg** total design target. The shell alone could consume most of the lower bound.

The actual panel set must therefore:

- avoid duplicate hidden skins;
- use structural openings and removable subpanels intelligently;
- drop to the 1.0 mm end of the gauge range wherever stiffness testing allows;
- add local doublers only at exposed and frequently handled areas rather than raising the gauge globally;
- maintain a formal mass budget before panel release.

The complete robot will exceed the 12–25 kg target unless actuators, battery, frame, compute and bodywork are tightly mass-controlled. No panel geometry should be released until the mass budget exists.

## Joining and finish

- Prefer bolted, riveted, or replaceable jointing around service areas.
- The subframe is **TIG welded** from 6061-T6: 20 × 40 × 2.5 wall rails and 20 × 20 × 2.0 wall cross and depth members. See the welded-strength rule below.
- Use structural adhesive only as a secondary load path unless specifically qualified.
- Use anodising, powder coat, or conversion coating on the chassis and the exterior panels, selecting a finish system compatible with both alloys.

## Welding the subframe

The frame is TIG welded rather than bolted from T-slot profile. Three consequences follow, and the first is the one that governs the design.

### Design to the welded allowable, not the T6 figure

Welding anneals 6061-T6 locally. Yield in the heat-affected zone falls from about **276 MPa to roughly 145 MPa**, a **47 per cent** reduction, and the affected band reaches around 25 mm either side of a weld. On 20 mm members that means most of a joint region is softened.

| Section | Area | Parent yield load | As-welded |
|---|---:|---:|---:|
| 20 × 40 × 2.5 rail | 275 mm² | 75.9 kN | **39.9 kN** |
| 20 × 20 × 2.0 member | 144 mm² | 39.7 kN | **20.9 kN** |

Full T6 recovery needs solution treatment near 530 °C, quench and artificial ageing. That is impractical for a one-metre welded frame and would distort it. Natural ageing recovers part of the loss over several weeks, to roughly T4, but the design must not depend on it.

**No stress analysis has been performed on this frame.** Wall thicknesses were chosen to match commercial extrusion mass, not from load cases. Welding makes that gap more consequential, because the joints are now the weakest regions rather than the strongest.

### Alloy note

6061 is entirely weldable and is the usual choice for welded tube frames, but it is not the strongest choice *as welded*. The 5xxx series is work-hardened rather than heat-treated, so it has no comparable softening problem: 5083-H111 retains essentially its full strength through a weld, which lands it close to welded 6061 despite a lower parent figure. If sourcing allows, it is worth comparing before committing.

### Practical requirements

- **Machine the bearing bores after welding.** The hip bulkheads carry the joint bores, and welding rails to them puts a heat-affected zone directly at the bore. Boring afterwards is the only way to hold alignment.
- **Build in a jig.** Twenty-eight members and thin walls distort readily; a fixture and a planned weld sequence are needed, not optional.
- **Filler:** 4043 is more forgiving and less crack-prone; 5356 gives higher joint strength. Choose deliberately.
- **2.0 mm wall is thin for TIG.** It welds, but burn-through at corners is a real risk and argues for a skilled hand or a thicker member at the most loaded joints.

Welding does remove the corner brackets and T-nuts a bolted frame would need, which is a small mass saving not previously counted.

## Decals and markings

Printed vinyl decals carry the identity and, more importantly, the safety markings. Artwork is held at `website/public/images/gptars-decal-sheet.svg`, drawn 1:1 in millimetres on an A2 sheet.

GP-TARS V2 decal sheet

Applied, in three-quarter view. The camera and every decal position are
projected from `cad/parameters.py` by `cad/render_hero.py`, so this cannot drift
from the model:

GP-TARS V2 with its decals applied

Placement on the robot, front and rear:

GP-TARS V2 decal placement on the front and rear elevations

| Decal | Size (mm) | Purpose |
|---|---|---|
| TARS vertical wordmark | 52 × 250, ×2 | Port and starboard identity, two colourways |
| Data plate | 120 × 72 | Build, height, mass class, bus voltage, alloys, unit number |
| Hazard triangles | 44 × 40, ×4 | Crush, 24 V live, hot surface, starts without warning |
| E-stop surround | Ø70 | Centre cut for the mushroom head |
| Service labels | 130 × 16, ×4 | Compute, GPU and battery access, plus isolate-before-opening |
| Pinch-point stripes | 344 × 14, ×2 | Limb leading edges and the hip gap |
| Panel index marks | 26 × 26, ×8 | Return each panel to the opening it came from |
| Display surround | Scales to the 268 × 476 aperture | Bezel trim |

Application rules:

- Convert the artwork to the printer's CMYK profile; the source is RGB.
- Use matte or satin vinyl. Gloss reflects badly under exhibition lighting.
- Laminate everything. The limbs strike the ground every gait cycle.
- Degrease with isopropyl alcohol. Do not apply over fresh anodising or uncured powder coat.
- Keep decals 10 mm clear of panel edges and fasteners so they survive removal.
- The hazard stripes and E-stop surround are function rather than decoration, and must be applied before any powered test.

The hazard pictograms follow ISO 7010 geometry but are not certified labels. Source certified labels wherever compliance is actually required.

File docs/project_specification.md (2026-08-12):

# GP-TARS V2 — 1 Metre Walking Robot CAD Project

We are building a full-size robotic version of GPTARS based on:

[https://github.com/poboisvert/GPTARS_Interstellar](https://github.com/poboisvert/GPTARS_Interstellar)

This is **not** a static prop and not simply an enlarged version of the original hobby-servo robot.

The target is:

**GP-TARS V2 — an approximately 1,000 mm tall, self-propelled walking TARS-style robot with onboard local AI compute.**

## Source Files

The project workspace should contain or be given access to:

* Original GPTARS repository
* `GPTARS_Interstellar-main.zip`
* `GP_TARS_V2_1000mm_scaled.brep`
* `GP_TARS_V2_1000mm_CAD_README.txt`

The existing GPTARS design is the visual and kinematic reference.

The original full robot geometry measured approximately:

* Tall axis: 250.35 mm
* Other dimensions approximately: 240 mm × 65 mm

The external geometry has initially been uniformly scaled by:

**3.9943785**

to produce an exact overall height of:

**1000 mm**

Do not assume that original screw holes, servo mounts, wall thicknesses, shafts, bearings or internal mechanisms should also remain scaled.

The scaled model is only the **external dimensional reference**.

---

# MAIN PROJECT OBJECTIVE

Create a new parametric CAD design named:

# GP-TARS V2 1000

The robot must:

* remain visually recognisable as TARS
* stand approximately 1000 mm tall
* reproduce TARS-style articulated walking
* support its own weight
* turn left and right
* execute controlled pivoting
* recover to vertical
* contain onboard batteries
* contain onboard computer hardware
* contain an NVIDIA GPU
* contain real-time motor control electronics
* be serviceable
* have removable panels
* use metal structural components
* use removable panels primarily as cosmetic bodywork

The mechanical structure must NOT rely on body panels of any material for primary structural loads.

> **Revision, 2026-08-10 — bodywork material superseded.** This specification
> originally called for printed PETG/ASA/CF cosmetic panels. Production bodywork
> is now formed 5052-H32 aluminium sheet. See `docs/aluminium_architecture.md`
> for the material schedule and the mass consequence recorded below.
>
> The load-path rule is unchanged and matters *more* under this decision: formed
> aluminium panels look structural and must still never be treated as such.

---

# CAD DESIGN PHILOSOPHY

Separate the design into:

1. External cosmetic shell
2. Internal aluminium skeleton
3. Walking joints
4. Actuator assemblies
5. Bearings and shafts
6. Battery compartment
7. Compute compartment
8. GPU compartment
9. Electronics compartment
10. Cooling system
11. Sensors
12. Wiring channels
13. Service panels
14. Safety systems

Maintain the original TARS proportions wherever mechanically practical.

---

# PARAMETRIC MASTER VARIABLES

Create a master parameter/configuration file.

Use millimetres unless otherwise specified.

Initial parameters:

```text
ROBOT_HEIGHT = 1000

SHELL_WALL = 1.2
SHELL_WALL_MIN = 1.0
SHELL_WALL_MAX = 1.6

FRAME_PROFILE_SMALL = 20
FRAME_PROFILE_LARGE_X = 20
FRAME_PROFILE_LARGE_Y = 40

MAIN_SHAFT_DIAMETER = 20
SECONDARY_SHAFT_DIAMETER = 12

MAIN_ACTUATOR_CONTINUOUS_TORQUE = 60 Nm minimum design target
MAIN_ACTUATOR_PEAK_TORQUE = 100 Nm minimum initial design target

SECONDARY_ACTUATOR_TORQUE = 10–25 Nm

BATTERY_VOLTAGE = 12.8 V   (LiFePO4 main bus)

GROUND_CLEARANCE_TARGET = 10–25 mm

STRUCTURAL_MATERIAL = 6061-T6 aluminium

PANEL_MATERIAL =
5052-H32 aluminium sheet
```

Shell wall values are sheet gauges, not printed wall thicknesses. The superseded
printed specification was 3.0 mm nominal over a 2.5–4.0 mm range.

Do not permanently lock actuator torque until proper static and dynamic calculations are performed.

---

# STRUCTURAL DESIGN

Create a central aluminium structural chassis.

Preferred materials:

* 6061-T6 aluminium
* 20×20 extrusion where lightly loaded
* 20×40 extrusion or fabricated aluminium sections at primary load points
* CNC aluminium actuator brackets
* steel shafts at major pivots

Avoid relying on long printed pivot shafts.

Major loads must transfer:

```text
foot/contact surface
    ↓
lower frame
    ↓
joint shaft
    ↓
bearings
    ↓
actuator bracket
    ↓
central structural frame
```

The formed aluminium exterior should bolt onto the structural chassis through
isolated fixings, never becoming part of the load path.

---

# WALKING MECHANISM

The original GPTARS walking concept uses coordinated lifting, rotation and controlled falling/pivoting.

GP-TARS V2 should preserve this general movement but replace hobby servo open-loop control with closed-loop robotic actuators.

Primary walking sequence:

```text
STAND

→ SHIFT CENTRE OF MASS

→ UNLOAD / LIFT LEADING SECTION

→ ROTATE LEADING SECTION

→ CONTROLLED PIVOT

→ DETECT GROUND CONTACT

→ ABSORB LANDING

→ ROTATE BODY THROUGH

→ RECOVER TO VERTICAL

→ VERIFY STABILITY

→ NEXT STEP
```

Create CAD joint limits for every moving component.

Mechanical hard stops should exist before any joint reaches a physically damaging position.

Do not depend exclusively upon software travel limits.

---

# ACTUATORS

Do NOT use the original RC hobby servos.

Design around integrated BLDC robotic actuators containing:

* brushless motor
* reduction gearbox
* absolute or high-resolution encoder
* CAN communications
* current measurement
* torque/current limiting

Initial design envelope for main actuators:

```text
Diameter:
80–120 mm

Length:
50–100 mm

Continuous torque:
>= 60 Nm preferred

Peak torque:
>= 100 Nm preferred

Supply:
24 V at the actuator, from a step-up stage off the 12.8 V bus
```

The distribution bus is 12.8 V LiFePO4. Actuators are fed 24 V through
per-actuator boost modules, so the 24–48 V actuator market stays open without
running the whole robot at that voltage. See `docs/power_budget.md`.

Use placeholder actuator geometry initially so actuator brands can later be swapped.

Create actuator components such as:

```text
ACTUATOR_MAIN_PLACEHOLDER

ACTUATOR_SECONDARY_PLACEHOLDER
```

Do not design the chassis around one proprietary motor until the torque analysis is complete.

---

# MAIN PIVOTS

Use proper shafts and bearings.

Initial main pivot:

```text
20 mm steel shaft
```

Suggested bearing starting point:

```text
20 mm ID sealed bearings
```

Use two bearings where practical to resist moment loads rather than cantilevering joints off a single bearing.

Design replaceable bearing carriers.

---

# COMPUTE SYSTEM

The robot will contain a high-performance mini PC.

Allow approximately:

```text
220 mm × 220 mm × 80 mm
```

for the mini-PC installation envelope until exact measurements are inserted.

The computer will handle:

* local LLM
* vision
* speech recognition
* text-to-speech
* ROS 2
* navigation
* behaviour
* high-level motion requests

The computer must NOT directly control motor commutation or safety-critical joint control.

---

# LOCAL GPU

Design an onboard NVIDIA GPU compartment.

Do not assume a specific final GPU yet.

Initial envelope:

```text
GPU length = 300 mm
GPU height = 130 mm
GPU thickness = 60 mm
```

Make these CAD parameters:

```text
GPU_LENGTH
GPU_HEIGHT
GPU_WIDTH
```

GPU should preferably be mounted vertically.

Provide:

* intake airflow
* exhaust airflow
* removable GPU bracket
* PCIe/OCuLink cable path
* protection from vibration
* access without dismantling the complete robot

The GPU mount should support a card approximately equivalent in size to a modern 2–3 slot NVIDIA GPU.

---

# COOLING

Create a bottom-to-top airflow path.

Preferred layout:

```text
LOW AIR INTAKE
      ↓
FILTER
      ↓
GPU
      ↓
MINI PC
      ↓
EXHAUST FANS
      ↓
HIGH EXHAUST
```

Keep motor-controller cooling separate where practical.

Add fan mounting locations.

Initial fan sizes to consider:

* 80 mm
* 92 mm
* 120 mm

Do not compromise structural members for airflow.

---

# BATTERY

Battery should be positioned as low as possible.

Initial system voltage:

**24 V**

Create a configurable battery envelope approximately:

```text
300 mm wide
150 mm deep
120 mm high
```

This is only a placeholder until battery energy requirements are calculated.

Battery tray requirements:

* bolted metal tray
* retaining strap
* removable
* protected from GPU heat
* protected from actuator impact
* accessible charging connector
* fused main output
* manual disconnect

The battery location should lower the centre of gravity.

---

# ELECTRONICS

Provide mounting areas for:

* real-time motor controller
* CAN interface
* power distribution
* motor fuses
* contactors
* DC/DC converters
* IMU
* emergency-stop controller
* cooling controller
* network switch if needed

Possible real-time controller:

* STM32
* Teensy
* similar deterministic MCU

Architecture:

```text
MINI PC
   │
USB / Ethernet / CAN
   │
REAL-TIME CONTROLLER
   │
CAN BUS
   │
BLDC ACTUATORS
```

---

# SAFETY

The mechanical model must include provision for:

## Physical emergency stop

Large mushroom E-stop.

The E-stop should disable actuator power independently of the local LLM or operating system.

Also design:

* actuator power contactor
* main battery disconnect
* fuse panel
* joint mechanical hard stops
* accessible service disconnect

Do not place E-stop somewhere that becomes inaccessible while the robot is moving.

---

# SENSORS

Reserve mounting provisions for:

* IMU
* front RGB camera
* depth camera
* microphone array
* ToF sensors
* ground contact sensors
* joint encoders
* optional LiDAR

Do not permanently model specific sensors yet unless required.

Use replaceable mounting plates.

---

# CENTRE OF GRAVITY

Create CAD reference points for:

```text
COG_STATIC

COG_BATTERY

COG_GPU

COG_COMPUTE
```

Use component masses when available.

The CAD project should eventually calculate approximate overall centre of gravity.

Keep heavy components centred laterally.

Place the battery below the GPU and computer where possible.

---

# BODY PANELS

Use the existing scaled TARS geometry as reference surfaces.

Redesign external panels instead of simply scaling the old STL wall thickness.

Preferred panel thickness:

```text
1.0–1.6 mm formed 5052-H32 sheet, 1.2 mm nominal
```

Use folded returns, swaged beads and local doublers to control panel flex rather
than increasing gauge. Ribbing a printed panel and stiffening a sheet-metal panel
are not the same problem.

Panels should be removable using:

* M3
* M4
* M5

fasteners depending on location.

Use rivnuts, nut plates or captive fasteners in the sheet. Heat-set inserts no
longer apply now that the bodywork is metal.

Isolate the panels from the 6061-T6 chassis where dissimilar-metal or
fastener-bearing contact could cause galvanic corrosion or fretting.

Structural joints should use bolts into aluminium or steel.

## Mass consequence

A complete 1.2 mm skin over the rectangular envelope is approximately 9.4 kg
before formed returns, doublers and hardware, against a 12–25 kg total design
target. Panel geometry, openings and a controlled mass budget must therefore be
established before any bodywork is released. See `docs/interference_report.md`.

---

# SERVICEABILITY

Major areas should be accessible separately.

Create panels for:

```text
COMPUTE ACCESS

GPU ACCESS

BATTERY ACCESS

MOTOR CONTROLLER ACCESS

LEFT ACTUATOR ACCESS

RIGHT ACTUATOR ACCESS
```

Aim to replace the GPU or mini PC without removing the walking mechanism.

Aim to replace an actuator without completely disassembling the body.

---

# CAD COMPONENT TREE

Use a clean assembly hierarchy.

Recommended structure:

```text
GP_TARS_V2_1000
│
├── 00_MASTER_REFERENCE
│
│   └── Original_1000mm_Scaled_Geometry
│
├── 01_FRAME
│   ├── Central_Spine
│   ├── Left_Frame
│   ├── Right_Frame
│   └── Crossmembers
│
├── 02_JOINTS
│   ├── Upper_Pivot
│   ├── Lower_Pivot
│   ├── Left_Leg_Pivot
│   └── Right_Leg_Pivot
│
├── 03_ACTUATORS
│
├── 04_BEARINGS_SHAFTS
│
├── 05_BATTERY
│
├── 06_COMPUTE
│
├── 07_GPU
│
├── 08_ELECTRONICS
│
├── 09_COOLING
│
├── 10_SENSORS
│
├── 11_BODY_PANELS
│
├── 12_FASTENERS
│
└── 13_WIRING
```

---

# SOFTWARE / CAD AUTOMATION

Where possible, generate geometry parametrically using Python.

Preferred options:

* CadQuery
* FreeCAD Python
* Fusion 360 Python API

Create scripts under:

```text
cad/
```

Suggested structure:

```text
cad/
├── README.md
├── parameters.py
├── gp_tars_master.py
├── frame.py
├── actuator_placeholders.py
├── battery.py
├── compute.py
├── gpu.py
├── cooling.py
├── export.py
└── output/
```

Running:

```bash
python cad/export.py
```

should eventually generate:

```text
output/
├── GP_TARS_V2_MASTER.step
├── GP_TARS_V2_FRAME.step
├── GP_TARS_V2_ASSEMBLY.step
└── STL/
```

Do not overwrite original GPTARS source CAD.

---

# FIRST TASK

Do NOT attempt to completely redesign the robot immediately.

Perform this sequence:

## Stage 1

Inspect all original GPTARS CAD/STL/STEP files.

Document:

* component names
* external dimensions
* moving components
* original pivot locations
* original servo locations
* original joint axes

Create:

```text
docs/original_geometry_analysis.md
```

---

## Stage 2

Import or reference the existing:

```text
GP_TARS_V2_1000mm_scaled.brep
```

and establish the 1000 mm body as the master external envelope.

Create datum planes and axes for:

* vertical centreline
* lateral centreline
* front/back centre
* main joint axes

---

## Stage 3

Create a simplified aluminium internal frame within the shell.

Do NOT create body panels yet.

Create space reservations for:

* actuators
* battery
* mini PC
* GPU
* controllers

---

## Stage 4

Generate an interference report.

Check:

* frame vs shell
* actuator vs shell
* GPU vs frame
* battery vs walking mechanism
* wiring clearance
* joint sweep clearance

Document this in:

```text
docs/interference_report.md
```

---

## Stage 5

Create engineering drawings showing:

* front view
* side view
* top view
* main dimensions
* joint axes
* actuator centres
* battery location
* compute location
* GPU location

---

# IMPORTANT

Do not simply create a four-times larger copy of the original hobby robot.

Use the original design for:

* appearance
* proportions
* articulation concept
* general motion concept

Redesign the internals as a real approximately 1 metre, 12–25 kg class autonomous walking robot.

Prioritise:

1. Mechanical safety
2. Stable walking geometry
3. Low centre of gravity
4. Structural stiffness
5. Serviceability
6. Thermal management
7. Appearance

Do not compromise structural integrity merely to preserve an internal feature of the original small-scale design.

Before making large design assumptions, document them in:

```text
docs/design_assumptions.md
```

Begin by inspecting the existing CAD files and reporting the exact geometry, component structure and proposed V2 joint locations before committing to the final internal frame.

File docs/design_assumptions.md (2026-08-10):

# Design assumptions and open decisions

## Status labels

- **Reference**: measured from source geometry.
- **Placeholder**: reserved envelope, deliberately replaceable.
- **Design target**: engineering objective requiring verification.
- **Open**: no commitment may be made yet.

## Current assumptions

1. The 1,000 mm target is the Y extent of the standing external reference envelope.
2. The exact imported STEP is normalised with scale `3.993658692`; the brief's BREP scale `3.9943785` remains unverified until the missing BREP is supplied.
3. X is lateral, Y vertical, and Z front/back.
4. Cosmetic proportions come from the scaled source; structural and purchased parts use real engineering dimensions.
5. Primary structure is 6061-T6 aluminium. Light framing may use 20×20 extrusion; primary load paths should start with 20×40 or fabricated/CNC sections.
6. Major shafts start at 20 mm steel, secondary shafts at 12 mm, both subject to bending and fatigue checks.
7. Each major pivot uses two separated sealed bearings where packaging allows. Cantilevered single-bearing joints are rejected as a baseline.
8. Main actuators remain placeholders until 12 V-compatible BLDC/CAN actuator selection and torque-speed-thermal analysis are complete.
9. Main torque targets of 60 N·m continuous and 100 N·m peak are not selections. They require mass, acceleration, impact-factor, lever-arm, and recovery-case calculations.
10. Design mass must now include the selected battery, compute hardware, display and optional external GPU explicitly; the previous 12–25 kg target may need revision after the real mass budget is built.
11. The canonical electrical architecture is now a **12.8 V nominal LiFePO4 main bus**.
12. Preferred current battery baseline is the **WattCycle 12.8 V 100 Ah Mini LiFePO4**, approximately 1,280 Wh. Larger 12.8 V packs are considered future capacity options only if their mass and packaging are acceptable.
13. The battery is mounted as low and central as joint sweep permits to minimise centre-of-gravity height.
14. Compute hardware is the **MINISFORUM AI X1 Pro-370**, 195×195×47.5 mm and approximately 1.5 kg, mounted vertically inside a 225×225×100 mm service/airflow keep-out.
15. Current preferred performance configuration is **32 GB system RAM plus NVIDIA RTX 2000 Ada Generation 16 GB** through OCuLink. RAM remains upgradeable to 64 GB or 128 GB.
16. The RTX 2000 Ada is modular, independently powered, cooled and removable. CAD should retain a preliminary 190×90×70 mm keep-out until the exact card + OCuLink dock assembly is measured.
17. The X1 Pro production chassis accepts AC mains at its internal power supply and has no exposed 19 V DC barrel input. Onboard DC operation should use the rear USB4 PD input at up to 100 W, subject to physical verification and sustained-load testing. A pure-sine inverter feeding the factory AC inlet is the fallback if 100 W PD proves insufficient.
18. Motor commutation and safety interlocks are handled by a deterministic MCU/CAN layer, not the mini PC or LLM.
19. Bottom-to-top compute airflow is preferred. Motor-controller cooling should be separated where practical.
20. Exterior bodywork is formed 5052-H32 aluminium sheet, nominally 1.2 mm with a 1.0–1.6 mm range, folded returns, beads, and local doublers.
21. Load-bearing structure, joint bulkheads, and actuator brackets use 6061-T6 aluminium. Steel remains required for shafts, bearing elements, and selected fasteners.
22. The earlier `TARS_1m_frame_layout_v1.f3d` is a packaging concept only. It is not approved for walking loads and must not be fabricated.
23. The **TV/display is mounted in the upper body/head area** and acts as the visual face of GP-TARS.
24. The display/camera interaction zone should target approximately **850–950 mm above ground** on the standing 1,000 mm robot, subject to final screen dimensions and shell geometry.
25. The display may be tilted rearward approximately **5–10 degrees** to improve viewing by standing adults while remaining visible to children.
26. The primary camera should be immediately above, beside, or closely integrated with the display so visual attention and displayed interaction feel co-located.
27. Microphones should be integrated into the upper display/sensor module where practical. Speakers may be in the same cassette or immediately below it.
28. The display/camera/microphone assembly should be designed as a removable service cassette and must not form part of the primary structural load path.
29. The current vertical packaging intent is: **display/sensors at top; mini PC and optional RTX 2000 Ada in the middle; power distribution/controllers below compute; battery low and central**.

## Decisions required before final frame commitment

- Supply and validate `GP_TARS_V2_1000mm_scaled.brep` or approve the measured STEP as the master envelope.
- Define walking degrees of freedom and reconstruct source motion with collision sweeps.
- Establish full mass budget and component mass estimates.
- Reconcile the aluminium panel mass, battery mass, compute hardware and actuator mass with the acceptable total walking mass.
- Calculate static holding, controlled-fall, landing, recovery, and fault load cases.
- Select 12 V-compatible actuator topology only after torque-speed-thermal analysis.
- Size main shafts, bearings, carriers, and brackets from calculated radial/axial/moment loads.
- Confirm the final battery model, connector, fuse, disconnect, contactor and charging architecture.
- Select and test the 12 V-to-100 W USB-C PD power path for the AI X1 Pro; use the factory AC inlet via a pure-sine inverter only if required by measured load.
- Select the exact OCuLink adapter/dock and regulated GPU power supply for the RTX 2000 Ada.
- Select the exact display model and freeze its active area, bezel, mounting pattern, mass, power draw and viewing angle.
- Freeze camera, microphone and speaker locations after the display is selected.
- Define fall-arrest/test-rig provisions for early walking tests.
- Establish joint hard-stop angles after shell and equipment sweep studies.

## Safety assumption

No unrestrained walking test is permitted from placeholder CAD. Initial motion testing requires an overhead restraint or other engineered fall-arrest fixture, independent E-stop power removal, conservative current limits, and a clear exclusion zone.

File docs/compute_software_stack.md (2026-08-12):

# Compute and software stack

Status: proposed stack, revision Stack V1, 2026-08-10.

This document specifies the Ubuntu and container architecture that runs on the
MINISFORUM AI X1 Pro-370, the onboard display and screen-sharing design, and the
memory, storage, power and thermal budgets that follow from them.

It covers layers 03 to 05 of `docs/software_architecture.md` only. Layers 01 and
02 — the hardwired E-stop loop, the actuator contactor and the deterministic
motion MCU — are hardware and firmware. Nothing in this document may become a
dependency of stopping the robot.

## Host baseline

| Item | Selection | Note |
|---|---|---|
| Distribution | Ubuntu 24.04 LTS, server (no desktop) | Matches ROS 2 Jazzy's supported platform |
| Kernel | Stock `linux-generic`, `PREEMPT` | Hard real-time lives on the MCU, not here |
| Container runtime | Docker Engine + Compose v2 | |
| GPU runtime | `nvidia-container-toolkit` | Required for CUDA inside containers |
| CAN | SocketCAN, `can0` brought up by systemd before Docker | |
| Time | `chrony`, with the MCU as a monotonic cross-check | Log correlation across a fall is worthless without it |

The mini PC runs no graphical session on the host. The onboard display is driven
from a container in kiosk mode (see *Human-machine interface*).

Isolate two CPU cores for the ROS 2 control path using `isolcpus` and pin the
`ros-control` container to them. Container overhead is namespacing, not
virtualisation, so throughput is unaffected — but scheduling jitter under a
loaded LLM is real, and the control loop must not compete with inference.

## Container inventory

Eleven containers. The split follows failure domain and update cadence, not
service granularity for its own sake; every additional split is another IPC hop
in a latency path.

### Tier 1 — robot core

Must start and run with no AI stack present.

| Container | Contents | Devices |
|---|---|---|
| `ros-control` | ros2_control, CAN hardware interface, URDF/`robot_state_publisher`, TF, state estimation | `can0` |
| `safety-supervisor` | Behaviour supervisor, fault state machine, MCU watchdog peer | `can0` (read), serial |

`safety-supervisor` is deliberately separate from `ros-control`. It must survive
an out-of-memory event or crash anywhere in the intelligence stack, and it should
be auditable and updatable independently. Give it a memory reservation, not just
a limit.

### Tier 2 — perception and interaction

| Container | Contents | Devices |
|---|---|---|
| `llm-server` | llama.cpp CUDA server, OpenAI-style API | NVIDIA GPU |
| `vision` | Camera pipeline, depth, detection and recognition | V4L2, depth camera, NVIDIA GPU |
| `speech` | Wake word, STT and TTS as one pipeline | ALSA/USB audio |

`speech` is intentionally one container. Wake word, transcription and speech
output chain directly, and barge-in is latency-critical; splitting them adds
round trips to the path a person actually feels.

### Tier 3 — behaviour, data and interface

| Container | Contents | Devices |
|---|---|---|
| `tars-ai` | Persona, message router, memory orchestration, skill registry | — |
| `memory` | Vector store and embeddings | Data volume |
| `hmi` | Onboard display UI in kiosk mode | DRM/KMS or remote panel |
| `streaming` | WebRTC/RTSP/HLS server for screen sharing | iGPU encoder |

### Tier 4 — operations

| Container | Contents |
|---|---|
| `observability` | Log and metric shipping, rosbag recording, health endpoints |

A robot that falls over without a recording is a robot that falls over twice.

### Reduced sets

- **First bring-up (5):** `ros-control`, `safety-supervisor`, `observability`,
  `hmi`, `streaming`. No AI at all until joints move under supervision.
- **Permanent merge candidate:** fold `hmi` into `tars-ai` if the interface stays
  a thin web client.

## Networking model

All containers run with `network_mode: host`.

ROS 2 discovery is DDS multicast, which bridged Docker networking breaks. Host
networking is standard practice for robots and is assumed throughout. The
consequence must be understood: isolation between these containers is process,
filesystem and cgroup, **not** network. Any container can reach any ROS 2 topic.

The LLM command boundary in `docs/software_architecture.md` is therefore enforced
in `safety-supervisor`, not by network segmentation. Do not weaken it on the
assumption that containers cannot see each other.

Grant devices explicitly with `--device`. No container in this stack runs
`--privileged`; a privileged container adjacent to a safety system defeats the
authority boundary the whole architecture exists to create.

## GPU allocation

The external NVIDIA card is the scarce resource, and `llm-server` and `vision`
both want it. VRAM, not system RAM, is the binding constraint on this robot.

| VRAM | What it supports |
|---|---|
| 16 GB | A 14B-class model at Q4 (~9 GB) plus vision (~3 GB). Workable, but the two compete and context length is limited |
| 24 GB | A 32B-class model at Q4, or a 14B model with comfortable vision headroom and long context |

24 GB is the better buy if the bay and its independent supply allow it. It is
cheaper than discovering after the GPU bracket is fabricated that vision and the
language model cannot co-reside.

Set explicit VRAM limits per container rather than letting both allocate freely.
An OOM inside CUDA during a walking trial is a fault case, not an inconvenience.

Video encoding for screen sharing uses the **Radeon 890M integrated GPU** via
VA-API, not the NVIDIA card. This keeps encode traffic off the OCuLink PCIe 4.0
x4 link, leaves NVENC free, and keeps the display pipeline local to whatever
drives the panel.

## Human-machine interface

### What the source geometry already contains

The imported GPTARS assembly contains `Screen`, `Screen Protector` and a
`Screen support` under `Chassis / Upper Lid`. A display is original design
intent and V2 should scale that intent rather than invent a new location.

GP-TARS V2 dimensioned front and side elevations at the 480 x 1000 x 259.9 mm build size

### The constraint that sets the size

The central chassis measures 133.232 × 250.050 × 65.070 mm in the source and
**532 × 999 × 260 mm** at the 3.993659 reference scale, but the build width was subsequently narrowed to **240 mm** (see below). That is a large
front face, but it is not one rigid body: the upper and lower chassis articulate
about the main and secondary axles. Source axis heights are measured from a base
at `SOURCE_Y_MIN = -10.366961`, so height above ground is
`(Y_source - SOURCE_Y_MIN) x 3.993659`:

| Axle | Source Y | Scaled height (mm) |
|---|---:|---:|
| Upper secondary | 212.460 | 889.9 |
| Upper main | 199.460 | 838.0 |
| Lower secondary | 186.460 | 786.1 |
| Lower main | 142.585 | 610.8 |

These agree with `docs/interference_report.md`, which records the upper axes at
approximately Y=786–890 and the lower main axis near Y=611.

The Upper Lid volume above the upper secondary axle is therefore
**240 mm wide by only 110 mm tall**. A display must fit inside one rigid section;
nothing may span an articulating axle.

### Recommended display

The Upper Lid therefore admits only a wide bar panel, roughly 210 × 85 mm of
usable aperture. **The display is not placed there.**

Reference footage of a working replica mounts its screen on the **main front face
of the lower chassis** instead, and that is the better location. The front face
below the hip axis is a single rigid section approximately **240 mm wide by 600 mm
tall**, which is a far larger canvas than the lid.

| Location | Usable aperture | Verdict |
|---|---|---|
| Front face, below the hip axis | ~240 × 600 mm | **Selected.** Admits a full portrait panel |
| Upper Lid, above Y=889.9 | ~210 × 85 mm | Bar panels only |
| Between the lower axes, Y=611–786 | 240 × 175 mm | Too shallow once structure is allowed for |

The modelled aperture is a **15.6 inch portrait panel, 194 × 345 mm active**,
positioned Y=130 to 475. It clears the hip axis at Y=610.8 comfortably, so no
panel crosses an articulating joint.

Panel size is set by the **240 mm chassis**, not by preference. With 23 mm of
margin each side for the panel return and aperture doubler, 194 mm is the widest
active area that fits. A 21.5 inch panel at 268 mm wide will not go in.

Reserve approximately **25 mm of Z depth** behind the aperture. The mini PC and
GPU reservations sit deeper in the body, so there is no depth conflict, but the
25 mm still comes out of the 259.9 mm total that `docs/interference_report.md`
lists as risk 1.

### The cable problem solves itself

An earlier revision of this document placed the display in the Upper Lid and
concluded, correctly for that position, that no video cable should cross the
articulating axes.

Moving the display to the lower chassis front face removes the problem entirely:
the mini PC service envelope sits at Y=165–390 and the display at Y=100–576, so
**both are inside the same rigid section**. A direct HDMI or DisplayPort run from
the mini PC to the panel crosses nothing that moves.

This is a significant simplification. It removes the need for an Upper Lid
display controller, removes power and Ethernet from the joint crossing, and lets
the panel be driven natively at full resolution.

Reserve approximately **25 mm of Z depth** for panel, driver board, bonding and
cover. That comes directly out of the 259.9 mm body depth, which
`docs/interference_report.md` already lists as risk 1.

### Limb articulation

Reference footage of a walking replica shows the gait is a splay-and-close in the
sagittal plane: the slabs separate into leading and trailing groups, swing apart
into a wide A-frame, the body translates through, then they close. Every visible
rotation axis is horizontal and lateral, matching the X-parallel axles in the
source geometry. No yaw or roll degree of freedom is present.

Each outer slab bends mid-limb, so there are **two rotational degrees of freedom
per limb**: a hip at the lower main axis, Y=610.8, and a knee. The knee is
modelled at half the hip height, Y=305.4. That ratio is an engineering choice,
not a measurement from the source geometry, and it is parameterised as
`ARM_KNEE_RATIO` so it can move once the gait is reconstructed properly.

The splay is not a stylistic flourish. Standing, the fore-aft footprint is only
259.9 mm on a 1,000 mm robot, an aspect ratio of 3.8:1. Splaying converts that
into roughly an 800 mm base. **The splay is the stability mechanism**, which is
why the reference robot stands slightly splayed even at rest.

### Actuator sizing follows from the landing, not the stance

A static estimate: at 20 kg with the centre of gravity offset 200–300 mm
horizontally from the loaded hip, holding torque is 39–59 N·m. The 60 N·m
continuous target covers that.

But every gait cycle ends in a controlled fall and catch. Applying a 2–3 impact
factor puts the landing case at **80–180 N·m**, which brackets and may exceed the
100 N·m peak target. The landing also sizes the shafts, bearings and brackets.

These are order-of-magnitude figures from stated assumptions, not a dynamic
analysis. They are recorded to show that the peak torque target is the number at
risk, and that it must not be frozen without proper simulation.

### As modelled

The bodywork and leg-arm slabs exist in
`cad/output/GP_TARS_V2_R10.f3d` as 90 bodies across
`11_BODY_PANELS` (14) and `14_ARMS` (6):

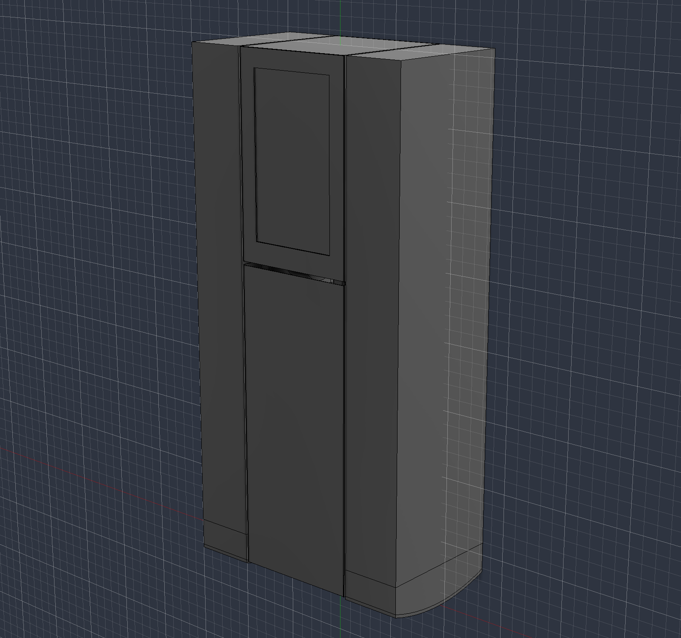
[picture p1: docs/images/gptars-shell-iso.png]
Fusion view of the GP-TARS V2 aluminium shell, service panels and leg-arm slabs


| Group | Bodies |
|---|---|
| Front | Lower, display, upper and lid |
| Rear | Battery, compute and GPU access, plus upper |
| Sides | Port and starboard, each split at the hip |
| Lids | Top and bottom |
| Leg-arms | Port and starboard, each as shin, thigh and upper |
| Display insert | Aperture doubler, cover lens, panel module, driver board |

Two rules drive that layout. **No panel crosses the hip axis at Y=610.8**, since
the upper and lower chassis articulate there; a 6 mm break straddles it. And
**service access is on the rear**, so the display is never removed to reach the
GPU or the mini PC.

Each arm slab is 209.317 mm wide, leaving 4 mm running clearance to the central
chassis per side. All shells are modelled at the 1.2 mm sheet gauge. The display
aperture is cut through `PANEL_FRONT_DISPLAY` at 194 × 345 mm.

### The display insert

`15_DISPLAY` models what actually occupies the aperture, not just the hole:

| Body | Size (mm) | Note |
|---|---|---|
| `DISPLAY_APERTURE_DOUBLER` | 230 × 381 × 2, holed | Restores the stiffness a 194 × 345 hole removes from 1.2 mm sheet |
| `DISPLAY_COVER_LENS` | 206 × 357 × 2 | Bonded behind the aperture, overlapping the doubler flange |
| `DISPLAY_PANEL_MODULE` | 223.8 × 359.5 × 5.5 | Bare 15.6 inch class panel outline, portrait |
| `DISPLAY_DRIVER_BOARD` | 110 × 65 × 12 | On standoffs behind the panel |

The stack consumes **22.9 mm** of depth against the 25 mm reservation, so it fits.

**Lateral clearance is the problem.** The chassis interior is 237.6 mm and the
panel module is 223.8 mm wide, leaving **6.9 mm per side**. That is enough for the
panel to pass but not for a mounting frame, edge retention or a cable exit at the
sides. Either the module hangs off the doubler alone, or the panel drops a size:
a 14 inch class module at roughly 323 × 202 mm would give about 17.8 mm per side.

The driver board was initially placed behind the panel and collided with the mini
PC service envelope by 45 × 38 × 5.5 mm. It now sits above both the PC envelope
and the GPU, at Y=490–555. Zero display conflicts remain.

Because the display and the mini PC are both in the lower chassis, the panel is
driven by a **direct HDMI run** from the PC. Nothing crosses a moving joint.

These are form and packaging bodies. They carry no fastener pattern, formed
returns, beads, hinges, bearings or joint hardware, the limbs have no feet or
contact pads, and none of them is releasable.

### Panel and safety consequences

- The bodywork is now formed 5052-H32 aluminium. A large display aperture removes
  significant stiffness from a 1.2 mm panel and requires a local doubler or a
  bonded subframe around the full opening.
- The gait involves controlled falling and landing. Do not fit ordinary cover
  glass. Use chemically strengthened thin glass or bonded polycarbonate, recessed
  behind the panel line, on compliant mounts.
- Mount the display away from the primary landing edge.
- The screen assembly needs its own service panel per the serviceability rules,
  with connector strain relief that does not cross a moving joint.
- Budget 300–800 g depending on size, against a 12–25 kg target in which the
  aluminium skin already accounts for approximately 9.4 kg.

## Screen sharing to Apple TV

### The problem, stated honestly

**There is no reliable open-source AirPlay screen-mirroring _sender_ for Linux.**
UxPlay and Shairport-Sync are AirPlay *receivers* — they make a Linux box a
target, which is the opposite of what is wanted here. Apple does not publish a
mirroring sender for Linux, and AirPlay 2 mirroring is authenticated.

Any plan that depends on the robot pushing an AirPlay mirror to an Apple TV
should be treated as unproven until demonstrated on the actual hardware. Do not
design the interface around it.

### Recommended approach: pull, do not push

Invert the direction. The robot continuously publishes its interface as a
network stream; the television pulls it on demand.

```text
hmi (web UI)
   │
   │ framebuffer or second headless render
   ▼
streaming container
   │  VA-API encode on Radeon 890M
   ├── WebRTC   → sub-second, for live operator view
   ├── RTSP     → VLC on tvOS, works today with no development
   └── HLS      → higher latency, most compatible
   ▼
Apple TV
```

Use `go2rtc` or MediaMTX in the `streaming` container; both serve WebRTC, RTSP
and HLS from one source and are well suited to an always-on publisher.

| Path | Effort | Latency | Notes |
|---|---|---|---|
| VLC on tvOS pulling RTSP | None — install and enter a URL | 1–3 s | Works today. Recommended starting point |
| Custom tvOS app | Apple Developer account, SwiftUI + WebRTC | < 1 s | Bonjour discovery, one-tap connect, polished |
| AirPlay mirroring from Linux | Unproven | — | Not recommended as a dependency |
| Chromecast instead | Low — mature Linux senders exist | 1–2 s | Only if the display target is negotiable |

"At any time" is satisfied by the stream always being available and advertised
over Bonjour/mDNS on the local network, with the television choosing when to
attach. This is more robust than a push model, because nothing on the robot has
to track or maintain a session with a device that may be off.

AirPlay **audio** is a separate and much easier case. RAOP senders for Linux do
exist, so routing TARS's speech to Apple TV speakers or AirPlay receivers is
achievable independently of video.

### Access control

The stream shows whatever the robot is doing and may include camera views. It
must not be an unauthenticated open port. Require a token or client certificate,
bind it to the robot's own network interface, and make it inoperable when the
robot is in a maintenance or fault state.

## Memory budget

| Component | RAM |
|---|---:|
| Ubuntu 24.04 headless and Docker daemon | 2.5 GB |
| `ros-control` and `safety-supervisor` | 2 GB |
| `vision` | 3 GB |
| `speech` | 3 GB |
| `llm-server` host side | 2–4 GB |
| `tars-ai` and `memory` | 3 GB |
| `hmi`, `streaming`, `observability` | 2.3 GB |
| **Steady state** | **~20 GB** |

Steady state is misleading on its own. Size for the peaks:

- `colcon build` on device: 4–8 GB with parallel jobs
- rosbag recording bursts
- page cache holding model files so a model swap does not stall on storage
- a second model resident during comparison

**Specification: 64 GB, as 2 × 32 GB DDR5-5600 SO-DIMM.** This fills both slots
and keeps dual-channel operation. 32 GB works but leaves no room to build,
record and infer at the same time. 96 or 128 GB is only justified if a model is
partially offloaded to CPU, which is a symptom of insufficient VRAM rather than a
design goal.

Set the Radeon 890M UMA allocation in firmware to the minimum (512 MB to 2 GB).
The discrete card performs inference; the integrated GPU only drives the display
pipeline and the video encoder, and should not reserve system memory it will not
use.

## Storage budget

| Consumer | Space |
|---|---:|
| Ubuntu and development tools | 30 GB |
| Docker images — CUDA bases are 6–8 GB each | 60–100 GB |
| Models: language, speech, vision, voices | 50–80 GB |
| ROS 2 workspace and colcon build artefacts | 20–30 GB |
| Swap | 16 GB |
| rosbag and stream recordings | 50–100 GB **per test session** |

Recorded data dominates and is the reason 1 TB fails in practice: it works until
walking trials begin, after which time goes into pruning logs instead of
diagnosing faults.

The AI X1 Pro-370 has **three M.2 2280 slots**. Use them by role:

| Slot | Size | Role | Requirement |
|---|---|---|---|
| 1 | 1 TB TLC | OS, Docker, models | Reliability and read speed |
| 2 | 2 TB TLC | rosbags, recordings, datasets | Write endurance; avoid QLC |
| 3 | — | Spare or expansion | Consider thermal cost before filling |

At roughly 10 GB per hour of logging, annual writes reach several terabytes, so
endurance matters more than peak sequential speed on the data drive.

## Power and thermal consequences

Two constraints from existing documents tighten as a direct result of this stack.

**Power.** `docs/compute_hardware.md` selects a 100 W USB-C PD source, now fed from the 12.8 V bus,
feeding the rear USB4 input, against an internal supply rated 134.9 W, and
already flags that sustained performance must be tested at that ceiling. This
specification adds 64 GB of DDR5, two or three NVMe drives at 5–8 W each under
load, and a display at 5–15 W. That consumes the remaining headroom and pushes
the decision towards the inverter option previously recorded as not preferred, or
towards accepting throttling. This must be measured, not assumed.

The GPU is unaffected: OCuLink carries no card power, so the graphics card and
its independent supply are a separate budget.

**Thermal.** `docs/project_specification.md` specifies airflow as intake, filter,
GPU, mini PC, exhaust. The mini PC therefore receives GPU exhaust as its intake
air. NVMe drives throttle at approximately 70 °C, and this places two or three of
them in pre-heated air inside a sealed aluminium body. Either duct the mini PC a
dedicated cold intake, or reorder the path so the PC sits upstream of the GPU.
Resolve this before the compute bay geometry is frozen.

The display adds a further heat source at the top of the body, where the
bottom-to-top airflow is already warmest.

## Open decisions

- Select the GPU. VRAM drives model choice, the vision/LLM split and the bay
  envelope; nothing downstream can be frozen first.
- Measure the compute stack against the 100 W PD limit, or approve the inverter.
- Resolve the mini PC intake air temperature before freezing the bay.
- Choose display size and type, then confirm the Upper Lid aperture against panel
  stiffness and the landing case.
- Confirm the Upper Lid controller and the power/Ethernet route across the upper
  main axle, including the service loop geometry.
- Demonstrate the chosen streaming path to a real Apple TV before committing the
  interface design to it.
- Define the stream authentication scheme and its behaviour in fault states.

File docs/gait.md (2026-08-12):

# Gait and locomotion

Status: proposed gait, revision Gait V1, 2026-08-11.

GP-TARS V2 walks as a **compass walker**: two rigid limbs hinged at a common
hip axis, swinging in the sagittal plane. Two actuators, two degrees of freedom,
no knees.

This is a deliberate simplification and a legitimate configuration. Compass
walkers are the classic passive-dynamic form, and rigid slabs pivoting about a
shared axis is closer to the screen robot's motion than a knee-jointed limb.
Earlier revisions of this project assumed two degrees of freedom per limb after
reading a mid-limb bend in reference footage of a fan-built replica; that replica
carries more articulation than the gait requires.

## Configuration

| Item | Value |
|---|---|
| Actuated joints | 2, one hip per side |
| Actuator | CubeMars AK45-10 V3.0 with a 32:1 second stage, 320:1 total |
| Joint torque | 80 N·m continuous, 224 N·m peak; 68 and 190 after efficiency |
| Limb | Rigid from hip to foot; no knee |
| Leg length | 610.845 mm, equal to the hip axis height |
| Plane of motion | Sagittal only |

The limbs are modelled as **single rigid shells** in `14_ARMS`, with the rockered
feet as separate parts in `16_FEET`.

GP-TARS V2 dimensioned front and side elevations, showing the hip axis, rockered feet and leg-arm slabs

## Step geometry

Step length is `2 L sin θ` for a splay half-angle θ about a leg of length L.

| Splay half-angle | Step length | Swing time at 0.6 rad/s | Speed |
|---:|---:|---:|---:|
| 10° | 212 mm | 0.58 s | 0.36 m/s |
| 15° | 316 mm | 0.87 s | 0.36 m/s |
| 20° | 418 mm | 1.16 s | 0.36 m/s |
| 25° | 516 mm | 1.45 s | 0.36 m/s |

Speed is **independent of splay angle**, because step length and swing time both
scale with θ. Walking speed is set purely by joint angular velocity, so it is a
function of actuator speed and bus voltage, not of gait tuning.

The actuators run at 24 V from a boost stage off the 12.8 V bus, so speed is
**0.36 m/s**, about 1.3 km/h. The 32:1 second stage costs some of the 0.48 m/s
the raw 24 V supply would give, and buys torque margin with it: 68 N·m against
the 53.3 N·m needed to hold a 20° splay at 33 kg.

**Working point: 20° splay, 418 mm step, 1.16 s per swing.**

## Foot clearance is the one real problem

A rigid leg of fixed length cannot swing past the stance leg without striking the
ground. This is the defining constraint of a kneeless walker, and it must be
solved mechanically because there is no joint available to solve it.

The answer is a **rockered sole, curved fore and aft only**. The sole is flat
across the limb's width; the rocker acts in the plane the limb swings in.

As the stance foot rolls, the arc centre stays at height R and the hip rides
highest when the leg is vertical, which is exactly when the swing limb passes.
Clearance is

```text
clearance = (L - R)(1 - cos θ)      L = 610.845 mm, the hip height
```

**not** `R(1 - cos θ)`. The distinction matters and inverts the intuition: a
larger radius raises the arc centre, shortens the effective pendulum and gives
**less** clearance, not more.

| Rocker radius | at 15° | at 20° | Sagitta over 259.9 | Stands unaided |
|---:|---:|---:|---:|---|
| 0, a sharp edge | 20.8 mm | 36.8 mm | — | No |
| 200 mm | 14.0 mm | 24.8 mm | 48.0 mm | No |
| 300 mm | 10.6 mm | 18.7 mm | 29.6 mm | No |
| **400 mm** | 7.2 mm | **12.7 mm** | **21.7 mm** | **Yes** |
| 500 mm | 3.8 mm | 6.7 mm | 17.2 mm | Yes |

### Radius is set by standing, not by clearance

A body rocking on a curved sole is stable only while its centre of mass sits
**below** the centre of curvature. Above it, the sole behaves like a rocking
chair and the machine tips instead of self-righting.

The estimated centre of mass is **381 mm** above ground. Any radius below that
leaves the robot unable to stand still without continuous active balancing,
which would defeat the power-off holding brakes the power budget depends on, in
the mode the robot spends most of its life in.

**Specify R = 400 mm**, which puts the arc centre 19 mm above the estimated
centre of mass and still yields 12.7 mm of swing clearance. The resulting sole
is far shallower than a small rocker: 21.7 mm of curvature across the 259.9 mm
depth rather than 48 mm.

The margin is thin and rests on an estimated centre of mass. **Compute the real
figure before the feet are made**, and re-check the radius against it; the
battery dominates that number and its final mounting height is not fixed.

A rocker also reduces heel-strike impact, which matters because the landing case
sizes the joint.

## What two joints will not do

The specification asks for behaviours this configuration cannot deliver:

| Requirement | With two hip joints |
|---|---|
| Walk forward | **Yes**, on flat ground |
| Turn left and right | **No.** Both limbs swing in one plane; there is no yaw freedom |
| Controlled pivoting | Limited to asymmetric stepping at best |
| Recover to vertical | **No.** Self-righting needs degrees of freedom this lacks |
| Step over obstacles | **No.** Clearance is fixed by the rocker geometry |

This is accepted for the current build, whose goal is forward walking. Turning
and recovery require either additional joints or a different mechanism, and
neither should be assumed to arrive by tuning software.
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

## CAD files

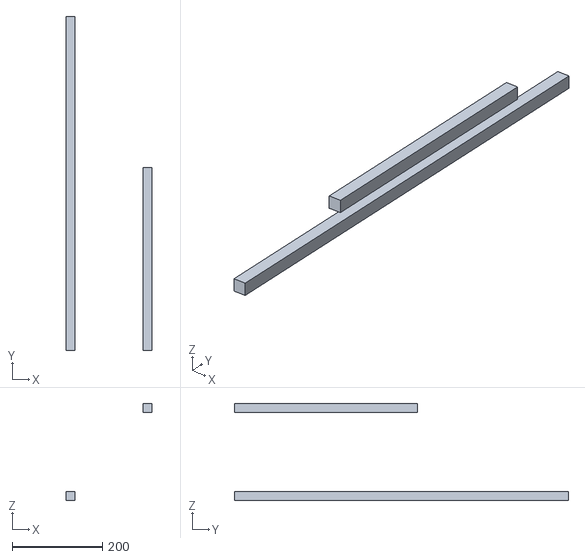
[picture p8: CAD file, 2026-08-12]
docs/models/gptars-wiring.stl
190.0 x 740.0 x 215.0

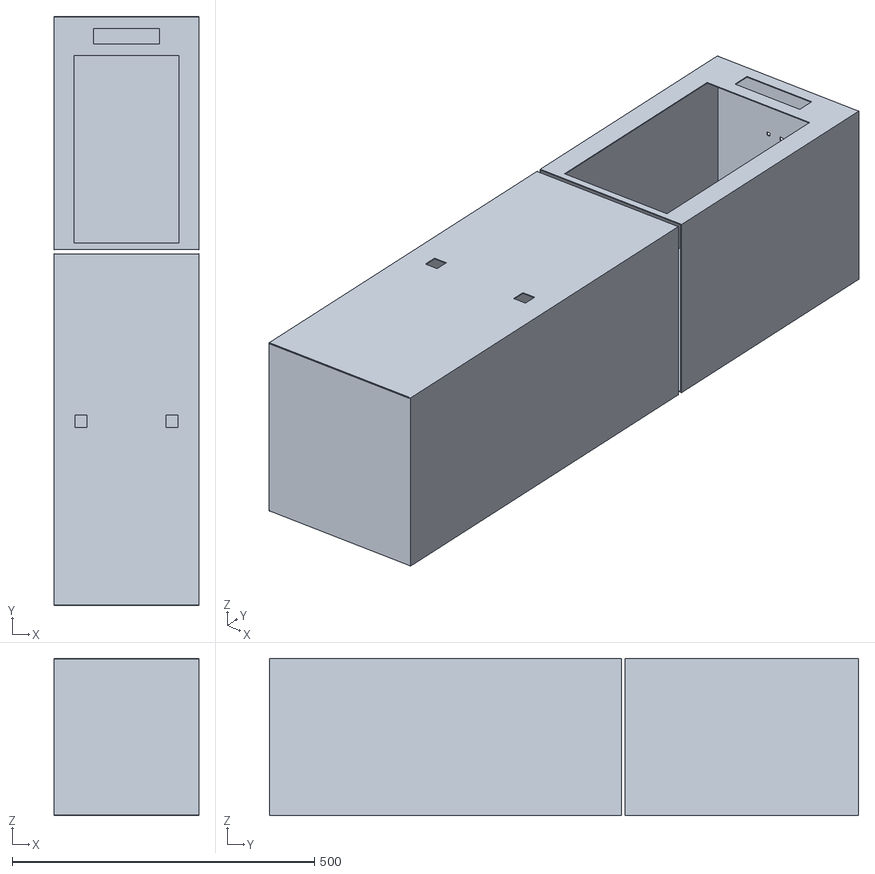
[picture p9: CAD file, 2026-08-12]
docs/models/gptars-panels.stl
240.0 x 975.0 x 259.9

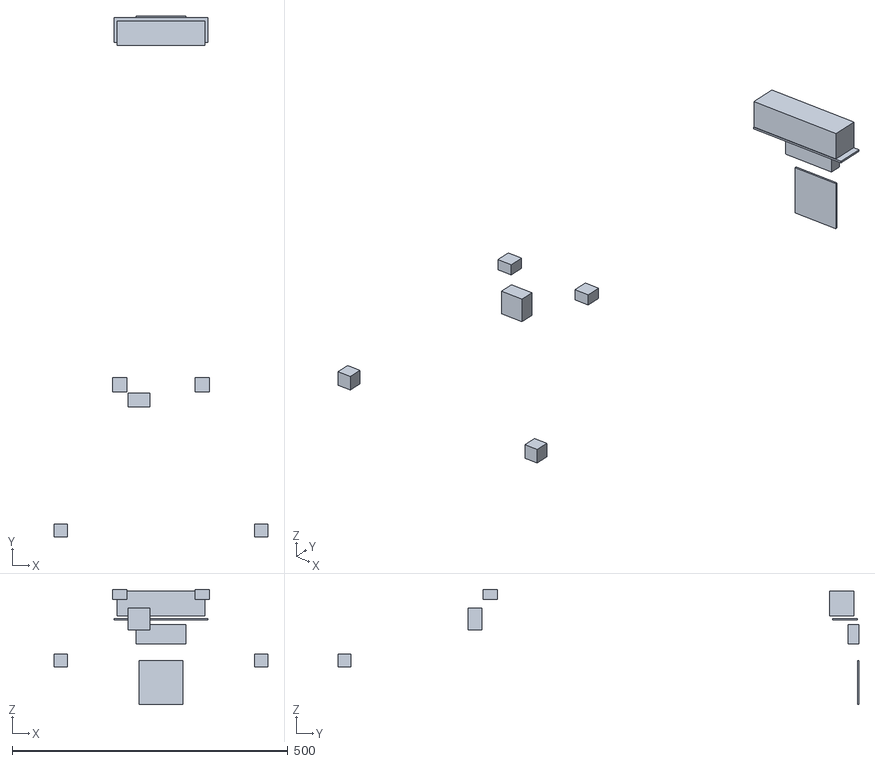
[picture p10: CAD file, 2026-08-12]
website/public/models/gptars-sensors.stl
388.0 x 944.8 x 208.7

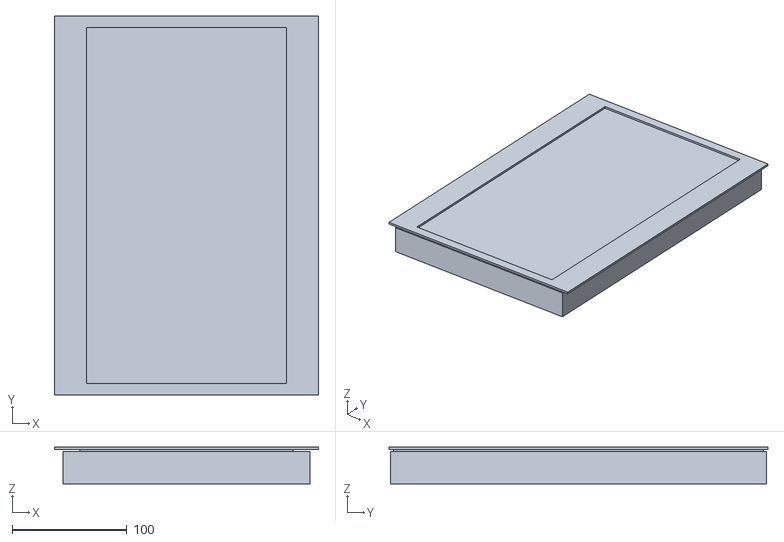
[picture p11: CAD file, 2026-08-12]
docs/models/gptars-display.stl
230.0 x 330.0 x 32.0

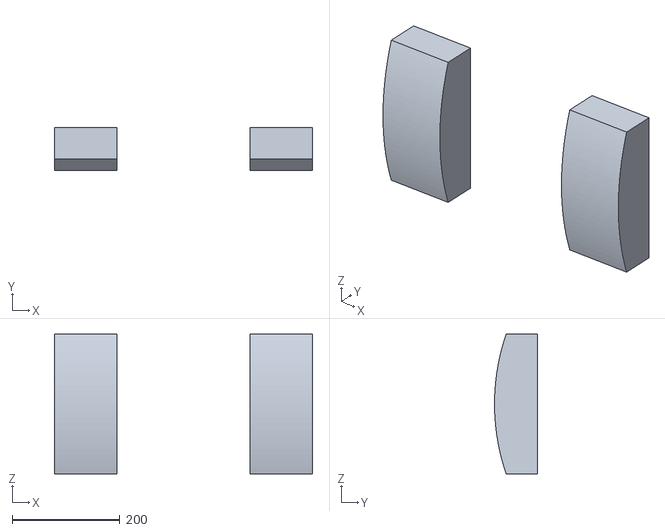
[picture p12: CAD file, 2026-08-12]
docs/models/gptars-feet.stl
480.0 x 80.0 x 259.9

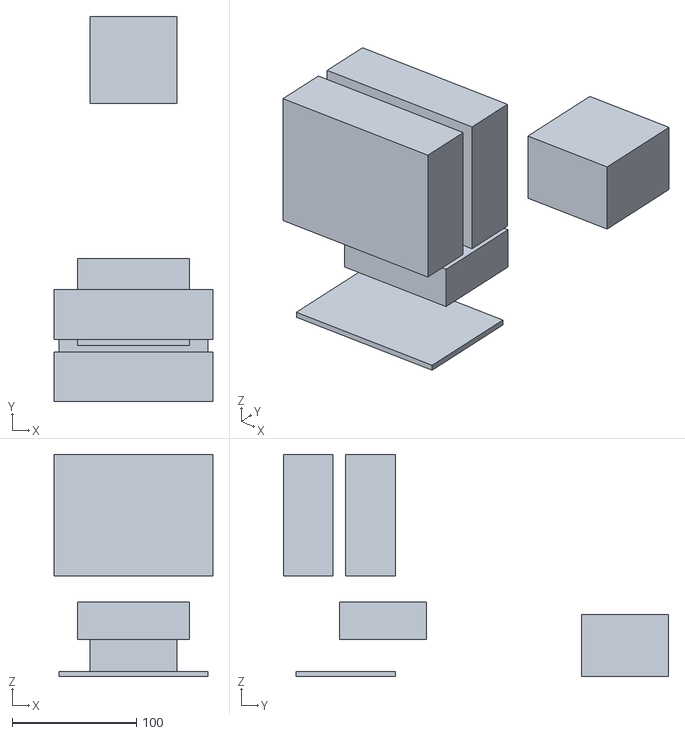
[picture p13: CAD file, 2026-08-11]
docs/models/gptars-electronics.stl
128.0 x 310.0 x 178.9

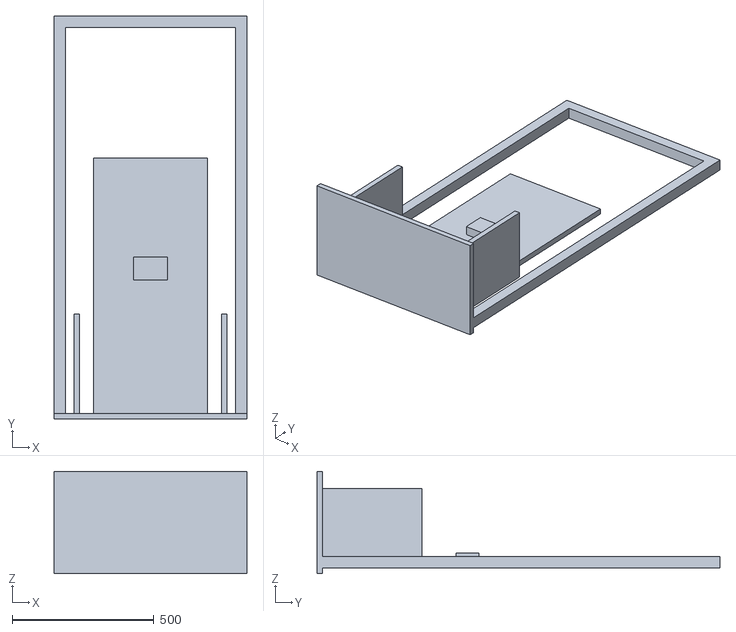
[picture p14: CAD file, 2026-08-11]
docs/models/gptars-dock.stl
680.0 x 1420.0 x 360.0

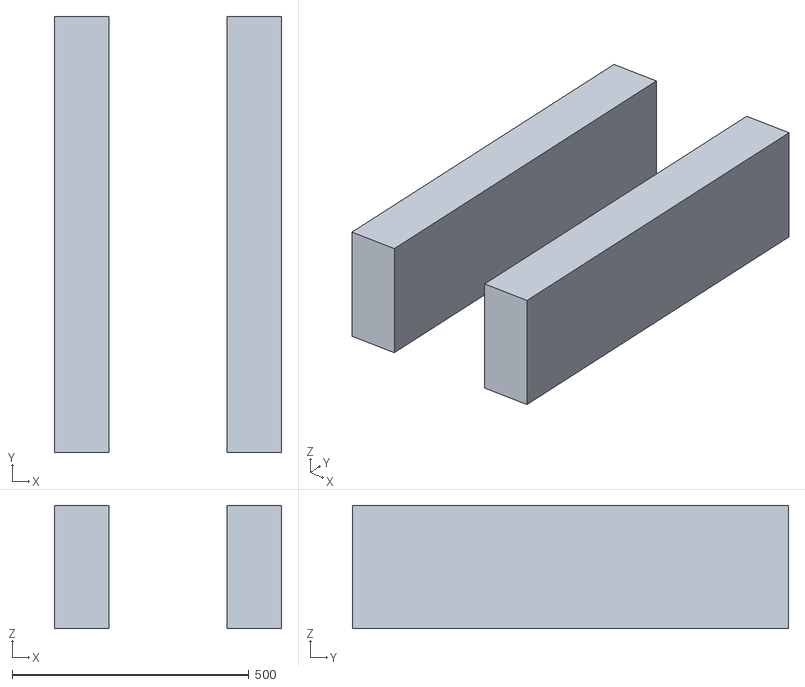
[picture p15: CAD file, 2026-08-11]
docs/models/gptars-arms.stl
480.0 x 920.0 x 259.9

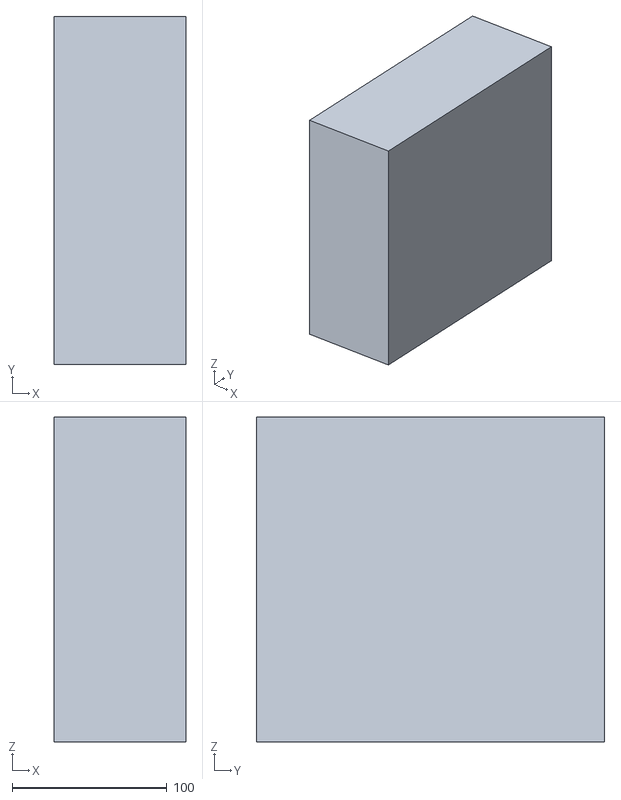
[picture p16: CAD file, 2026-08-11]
docs/models/gptars-compute.stl
85.0 x 225.0 x 210.0

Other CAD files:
cad/output/GP_TARS_V2_R09.f3d
cad/output/GP_TARS_V2_R10.f3d
docs/downloads/GP_TARS_V2_R09.f3d
docs/downloads/GP_TARS_V2_R10.f3d
docs/models/gptars-battery.stl
docs/models/gptars-drive.stl
docs/models/gptars-frame.stl
docs/models/gptars-gpu.stl
docs/models/gptars-joints.stl
docs/models/gptars-shafts.stl
website/public/downloads/GP_TARS_V2_R09.f3d
website/public/downloads/GP_TARS_V2_R10.f3d
website/public/models/gptars-battery.stl
website/public/models/gptars-drive.stl
website/public/models/gptars-frame.stl
website/public/models/gptars-gpu.stl
website/public/models/gptars-joints.stl
website/public/models/gptars-shafts.stl

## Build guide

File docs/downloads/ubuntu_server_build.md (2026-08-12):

# GP-TARS V2 Ubuntu Server build specification

Status: build blueprint, revision Server V1.

This document turns the software architecture into a reproducible host build. It is not yet an install script; it is the checklist and source of truth that the future install script and Ansible/automation should implement.

## Goal

Starting from a blank MINISFORUM AI X1 Pro-370, another person should be able to build the GP-TARS host without relying on undocumented decisions.

Target host:

- MINISFORUM AI X1 Pro-370
- AMD Ryzen AI 9 HX370
- 64 GB DDR5-5600
- 4 TB Lexar NQ780 NVMe
- NVIDIA RTX 2000 Ada 16 GB over OCuLink
- Ubuntu Server 24.04 LTS
- Docker Engine
- NVIDIA Container Toolkit / CUDA
- ROS 2 Jazzy

## Required end state

The completed host must:

1. boot headless without a desktop dependency
2. obtain network connectivity
3. expose only approved management ports
4. detect the RTX 2000 Ada with `nvidia-smi`
5. run a CUDA workload inside Docker
6. run GP-TARS Compose services automatically after boot
7. mount persistent data from stable host directories
8. start the top display service automatically
9. establish the host-to-safety-MCU heartbeat
10. keep motion disabled until safety readiness is confirmed
11. retain local conversation, speech, memory and vision when Internet access is unavailable
12. provide health, logs and diagnostics through the local management interface

## Installation phases

### Phase 1 — firmware and hardware verification

Before installing Ubuntu:

- update X1 Pro firmware/BIOS to an approved stable release
- confirm 64 GB RAM is detected
- confirm 4 TB NVMe is detected
- confirm OCuLink is enabled and RTX 2000 Ada is visible
- disable unnecessary automatic boot options that conflict with unattended robot startup
- record BIOS settings in the repository

### Phase 2 — Ubuntu Server

Install Ubuntu Server 24.04 LTS using a minimal/headless profile.

Baseline decisions:

- hostname: `gptars`
- system timezone: configurable; record deployed timezone
- SSH enabled using key authentication
- no public password SSH login in production
- automatic security updates enabled with a controlled reboot policy
- full disk encryption decision remains open because unattended robot boot and encryption-key handling must be reconciled

Partition/layout target:

```text
/                  OS and packages
/var/lib/docker    Docker images/containers/volumes
/opt/gptars        deployed application/configuration
/srv/gptars        persistent robot data
/srv/gptars/models AI model library
/srv/gptars/db     database storage/backup staging
/srv/gptars/logs   durable robot logs
```

Final filesystem and partition sizes should be set before implementation. A single 4 TB filesystem is acceptable for early development provided backups and Docker growth limits are enforced.

### Phase 3 — base packages

Install and record exact package versions or supported version ranges for:

- Git
- curl/wget
- build-essential
- Python 3 tooling
- chrony or system time synchronisation
- network diagnostic tools
- CAN utilities
- USB/serial utilities
- hardware monitoring tools
- NVMe health tools
- firewall tooling

Do not rely on manually installed packages that are absent from this document or the provisioning scripts.

### Phase 4 — NVIDIA and CUDA

Install an NVIDIA Linux driver supported by the RTX 2000 Ada and Ubuntu 24.04.

Acceptance check:

```bash
nvidia-smi
```

Must report the RTX 2000 Ada without driver errors.

Install NVIDIA Container Toolkit and configure Docker GPU support.

Container acceptance check must run a supported NVIDIA CUDA image and execute `nvidia-smi` inside the container.

CUDA toolkit installation on the host is optional if all CUDA applications run in containers. Prefer container-specific CUDA runtimes to reduce host coupling unless host-side development requires the toolkit.

### Phase 5 — Docker Engine

Install Docker Engine from the supported Docker repository rather than an ad-hoc desktop package.

Configuration requirements:

- Docker starts at boot
- GP-TARS service account has only the permissions it needs
- log rotation configured
- Docker data growth monitored
- NVIDIA runtime available
- restart policies defined in Compose
- container health checks defined for critical services

Primary Compose project:

```text
/opt/gptars/software/compose/docker-compose.yml
```

## GP-TARS container groups

### Core group

- `tars-core`
- `tars-personality`
- `tars-memory`
- `tars-api`
- `tars-telemetry`

### AI group

- `tars-llm`
- `tars-stt`
- `tars-tts`
- `tars-vision`

Only required AI containers receive GPU access.

### User experience group

- `tars-display`
- `tars-web`

### Robot group

- `tars-ros`
- `tars-motion`
- `tars-can`

Robot motion remains unavailable until the safety MCU and behaviour supervisor report ready.

## Container startup dependencies

Logical startup order:

```text
telemetry/database
        |
        v
memory + personality
        |
        v
LLM + STT + TTS + vision
        |
        v
TARS core
        |
        +--> display / web
        |
        +--> ROS 2 bridge
                 |
                 v
        safety MCU heartbeat
                 |
                 v
        motion availability
```

Docker startup order alone must not be treated as proof that a dependency is ready. Use health checks and application-level readiness probes.

## ROS 2 Jazzy

Install ROS 2 Jazzy using the official Ubuntu packages or a controlled container strategy.

Current preference: ROS 2 core host/container arrangement remains to be finalised after CAN and hardware-interface testing.

Required ROS packages will include:

- robot description / URDF tooling
- ros2_control
- controller manager
- joint state broadcaster
- trajectory controllers where appropriate
- diagnostics
- custom GP-TARS message/action packages

DDS implementation and network configuration remain open until latency and container networking are tested.

## Database and memory

Baseline:

- PostgreSQL
- pgvector

Persistent database data must not live only inside an ephemeral container layer.

Required data classes:

- user/person profiles
- personality settings
- permissions
- memory records
- learning progress
- semantic embeddings
- robot maintenance history
- faults and diagnostics references

Backups must be encrypted when they contain personal information.

## Personality and teaching configuration

The server must persist authorised user profiles and personality settings.

Baseline configurable settings:

```text
Humour: 0-100
Honesty/directness: 0-100
Verbosity: low/medium/high
Formality: casual/neutral/formal
Teaching mode: off/opportunistic/active
Age adaptation: automatic/manual
```

The personality service selects an age-appropriate interaction profile after identity resolution. If identity is uncertain it uses the neutral general-audience profile.

Learning progress must be stored separately from general conversational memory so it can be reviewed, reset or deleted independently.

## Networking

Default policy: local-first and deny unnecessary inbound access.

Expected interfaces may include:

- SSH for administration
- local HTTPS management UI
- WebSocket management/telemetry
- ROS 2/DDS internal networking
- NATS or MQTT internal event bus

Exact ports must be documented before firewall rules are frozen.

Cloud APIs are optional enhancements and must not be required for normal local conversation, vision, memory or robot safety.

## Secrets

Secrets must not be committed to GitHub.

Use environment files or a secrets manager for:

- API keys
- database passwords
- encryption keys
- external-service credentials
- administrator bootstrap credentials

Provide `.env.example` files containing names and safe defaults only.

## Display startup

Ubuntu Server remains headless, but the physical TARS display needs a lightweight graphics session.

The display build must define:

- graphics driver
- compositor/window system
- kiosk browser or native renderer
- display resolution/orientation
- auto-login/service strategy where required
- crash restart behaviour
- boot/self-test screen

The display process should be independently restartable without restarting the AI stack.

## Audio

The deployment must enumerate and lock stable audio device names for:

- microphone array
- speakers/amplifier

Container/device permissions must be explicit. Do not rely on whichever ALSA/Pulse/PipeWire device happens to become `default` after a reboot.

## Cameras

Camera devices must use stable udev names or IDs. Record:

- model
- USB path/device ID
- supported resolution/frame rate
- which service owns the camera

Vision should continue in a degraded mode if an optional camera is unavailable.

## CAN and MCU

The Ubuntu host does not directly provide the final safety authority.

Server setup must define:

- CAN interface hardware
- stable interface name, ideally `can0`
- bitrate/CAN-FD settings
- udev/systemd configuration
- host-to-MCU heartbeat protocol
- diagnostics tooling

Loss of host software must cause the MCU to place motion in the defined safe state.

## systemd services

Even though application workloads run in Docker, systemd should supervise host-level dependencies such as:

- CAN interface setup
- display session prerequisites
- GP-TARS Compose project startup
- hardware readiness checks where appropriate

Do not hide important boot dependencies inside shell profile scripts.

## Logging and telemetry

Record at least:

- boot/session ID
- container health/restarts
- CPU/GPU temperatures
- GPU utilisation and VRAM
- RAM usage
- NVMe health/temperature
- battery state
- actuator state/faults
- MCU heartbeat
- software version/commit

Define retention limits so logs cannot fill the 4 TB SSD indefinitely.

## Backup and restore

Back up:

- PostgreSQL data
- user/profile configuration
- personality settings
- learning progress
- calibration
- robot configuration
- selected long-term memories

Do not back up Docker image layers if they can be reproduced from versioned Compose/Dockerfiles.

A restore test is part of release validation.

## Updates

Application updates should be versioned and rollback-capable.

Preferred flow:

```text
pull approved release
build/pull container images
run configuration validation
stop affected services safely
apply database migrations
start new services
run health checks
rollback if acceptance fails
```

Motion must remain disabled during updates that touch ROS, CAN, motion, safety coordination or the behaviour supervisor.

## Security baseline

- SSH keys, not routine password login
- firewall enabled
- minimum exposed ports
- no secrets in Git
- containers run non-root where practical
- minimum device access per container
- GPU access only for required services
- read-only filesystem mounts where practical
- regular security updates
- management UI authentication
- per-user/role permissions

## Validation suite

The automated build is not complete until these tests pass:

### Host

- boot without keyboard/monitor
- network reachable
- correct storage mounted
- system clock valid

### NVIDIA

- `nvidia-smi` succeeds
- CUDA Docker container succeeds

### Docker

- all required containers healthy
- critical containers restart after forced failure
- persistent data survives container recreation

### AI

- local LLM responds
- STT transcribes test audio
- TTS generates speech
- vision receives a camera frame
- memory store/retrieve succeeds
- personality settings alter response style
- teaching profile changes explanation depth appropriately

### Robot boundary

- MCU heartbeat established
- motion remains disabled before readiness
- simulated heartbeat loss disables motion
- E-stop state is visible to host software

### Offline

Disconnect Internet access and verify local wake word, STT, LLM, memory, TTS, display and local management continue operating.

## Automation target

The eventual production build should be reproducible through a combination of:

- one documented Ubuntu installation baseline
- provisioning script or Ansible playbook
- versioned Dockerfiles
- versioned Compose files
- versioned configuration templates
- automated acceptance tests

The goal is that rebuilding the GP-TARS computer becomes a controlled deployment task rather than a one-off workshop setup.

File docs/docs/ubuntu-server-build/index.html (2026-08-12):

GP-TARS V2 · document 13 of 13

# GP-TARS V2 Ubuntu Server build specification

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

REVISED 12 Aug 2026SOURCE docs/ubuntu_server_build.mdSECTIONS 36WORDS 1,767

On this page

1. Goal
2. Required end state
3. Installation phases
4. GP-TARS container groups
5. Container startup dependencies
6. ROS 2 Jazzy
7. Database and memory
8. Personality and teaching configuration
9. Networking
10. Secrets
11. Display startup
12. Audio
13. Cameras
14. CAN and MCU
15. systemd services
16. Logging and telemetry
17. Backup and restore
18. Updates
19. Security baseline
20. Validation suite
21. Automation target

Download markdown ↓

Status: build blueprint, revision Server V1

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

## Goal

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

Target host:

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

## Required end state

The completed host must:

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

## Installation phases

### Phase 1 — firmware and hardware verification

Before installing Ubuntu:

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

### Phase 2 — Ubuntu Server

Install Ubuntu Server 24.04 LTS using a minimal/headless profile.

Baseline decisions:

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

Partition/layout target:

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

### Phase 3 — base packages

Install and record exact package versions or supported version ranges for:

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

### Phase 4 — NVIDIA and CUDA

Install an NVIDIA Linux driver supported by the RTX 2000 Ada and Ubuntu 24.04.

Acceptance check:

nvidia-smi

Must report the RTX 2000 Ada without driver errors.

Install NVIDIA Container Toolkit and configure Docker GPU support.

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

### Phase 5 — Docker Engine

Install Docker Engine from the supported Docker repository rather than an ad-hoc desktop package.

Configuration requirements:

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

Primary Compose project:

/opt/gptars/software/compose/docker-compose.yml

## GP-TARS container groups

### Core group

- tars-core
- tars-personality
- tars-memory
- tars-api
- tars-telemetry

### AI group

- tars-llm
- tars-stt
- tars-tts
- tars-vision

Only required AI containers receive GPU access.

### User experience group

- tars-display
- tars-web

### Robot group

- tars-ros
- tars-motion
- tars-can

Robot motion remains unavailable until the safety MCU and behaviour supervisor report ready.

## Container startup dependencies

Logical startup order:

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

## ROS 2 Jazzy

Install ROS 2 Jazzy using the official Ubuntu packages or a controlled container strategy.

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

Required ROS packages will include:

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

DDS implementation and network configuration remain open until latency and container networking are tested.

## Database and memory

Baseline:

- PostgreSQL
- pgvector

Persistent database data must not live only inside an ephemeral container layer.

Required data classes:

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

Backups must be encrypted when they contain personal information.

## Personality and teaching configuration

The server must persist authorised user profiles and personality settings.

Baseline configurable settings:

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

## Networking

Default policy: local-first and deny unnecessary inbound access.

Expected interfaces may include:

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

Exact ports must be documented before firewall rules are frozen.

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

## Secrets

Secrets must not be committed to GitHub.

Use environment files or a secrets manager for:

- API keys
- database passwords
- encryption keys
- external-service credentials
- administrator bootstrap credentials

Provide .env.example files containing names and safe defaults only.

## Display startup

Ubuntu Server remains headless, but the physical TARS display needs a lightweight graphics session.

The display build must define:

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

The display process should be independently restartable without restarting the AI stack.

## Audio

The deployment must enumerate and lock stable audio device names for:

- microphone array
- speakers/amplifier

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

## Cameras

Camera devices must use stable udev names or IDs. Record:

- model
- USB path/device ID
- supported resolution/frame rate
- which service owns the camera

Vision should continue in a degraded mode if an optional camera is unavailable.

## CAN and MCU

The Ubuntu host does not directly provide the final safety authority.

Server setup must define:

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

Loss of host software must cause the MCU to place motion in the defined safe state.

## systemd services

Even though application workloads run in Docker, systemd should supervise host-level dependencies such as:

- CAN interface setup
- display session prerequisites
- GP-TARS Compose project startup
- hardware readiness checks where appropriate

Do not hide important boot dependencies inside shell profile scripts.

## Logging and telemetry

Record at least:

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

Define retention limits so logs cannot fill the 4 TB SSD indefinitely.

## Backup and restore

Back up:

- PostgreSQL data
- user/profile configuration
- personality settings
- learning progress
- calibration
- robot configuration
- selected long-term memories

Do not back up Docker image layers if they can be reproduced from versioned Compose/Dockerfiles.

A restore test is part of release validation.

## Updates

Application updates should be versioned and rollback-capable.

Preferred flow:

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

## Security baseline

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

## Validation suite

The automated build is not complete until these tests pass:

### Host

- boot without keyboard/monitor
- network reachable
- correct storage mounted
- system clock valid

### NVIDIA

- nvidia-smi succeeds
- CUDA Docker container succeeds

### Docker

- all required containers healthy
- critical containers restart after forced failure
- persistent data survives container recreation

### AI

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

### Robot boundary

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

### Offline

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

## Automation target

The eventual production build should be reproducible through a combination of:

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

GP‑TARS V2 · GP-TARS V2 UBUNTU SERVER BUILD SPECIFICATIONRENDERED FROM docs/ubuntu_server_build.mdALL DOCUMENTS →

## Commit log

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2026-08-10 Publish the engineering docs as a living document site
    Make docs/*.md and cad/parameters.py the only sources of truth for the
    project, and render them directly into the website so the published
    figures cannot drift from the CAD source.
    Site:
    - Add a build-time Vite plugin that reads docs/*.md and cad/parameters.py,
    renders them, and mirrors the markdown into public/downloads. Editing a
    source file updates the site, the register and the downloads together.
    - Add /docs (document register), /docs/[slug] (each document with a TOC
    and anchored headings) and /parameters (all master variables, grouped,
    with derived values flagged).
    - Convert the overview sheet to a server component that re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
    [GP_TARS_V2_1000_ALUMINIUM_COMPUTE_V2.f3d, GP_TARS_V2_1000_ALUMINIUM_CONCEPT_V1.f3d]
2026-08-10 Add bodywork, leg-arms and an interactive STL model page
    CAD (Fusion, GP_TARS_V2_1000_ALUMINIUM_COMPUTE_V2):
    - Populate 11_BODY_PANELS with the formed 5052-H32 shell: five front
    service panels split by access area, two rear panels, both sides, top
    and bottom lids, all at the 1.2 mm sheet gauge on 1.5 mm seams.
    - Cut the bar-display aperture, 400 x 70 mm, through PANEL_FRONT_LID.
    - Add 14_ARMS with the port and starboard leg-arm slabs, each 209.317 mm
    wide with 4 mm running clearance to the chassis, and each split at the
    lower main axis into upper and lower 1.2 mm shells.
    - Export panels, arms and frame to STL.
    - Add /model, an interactive three.js STL viewer with per-group
    v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
    [gptars-arms.stl, gptars-frame.stl, gptars-panels.stl]
2026-08-10 Fix the STL viewer render error and default the site to dark
    The viewer built its canvas and legend inside an element React owned, so
    hydration failed as soon as those nodes appeared and the model page threw
    a render error. The container is now handed to React with
    dangerouslySetInnerHTML, which stops it reconciling that subtree, and the
    viewer boots on window load rather than DOMContentLoaded so hydration has
    finished first.
    Also harden the viewer: guard against a double boot, catch failures per
    container, and fall back to a readable message with the STL download
    links instead of an empty frame when WebGL is unavailable.
    Dark is now the default theme rather than a preference:
    - The served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
2026-08-10 Add limb knees, move the display to the front face, add decal artwork
    Reference footage of a walking replica shows the gait is a splay-and-close
    in the sagittal plane, and that each outer slab bends mid-limb. That is two
    rotational degrees of freedom per limb, where the CAD had one.
    CAD:
    - Rebuild 14_ARMS as shin, thigh and upper per side. The hip is the lower
    main axis at Y=610.8; the knee is modelled at half that height and is
    parameterised as ARM_KNEE_RATIO, since the source geometry does not
    record it.
    - Rebuild 11_BODY_PANELS to 14 panels under two rules: no panel crosses
    the hip axis, because the upper and lower chassis articulate there, and
    service access moves to the rear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
    [gptars-arms.stl, gptars-panels.stl]
2026-08-10 Add a decals page to the site
    The decal artwork was only reachable inside the architecture document.
    Give it a route of its own alongside the 3D model, since it is a
    fabrication asset rather than background reading.
    - Add /decals: the sheet at 1:1, a contents table with sizes and
    quantities, the print and fitting rules, and SVG download.
    - Frame the sheet on a light surround so the white print artwork reads
    correctly against the dark page.
    - Add the route to the navigation on every page and to the static export.
    Restate on the page that the hazard pictograms follow ISO 7010 geometry
    but are original artwork carrying no certification, and that the
    pinch-point stripes and E-stop surround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
2026-08-10 Narrow the body to 480 mm and repack the equipment
    Reference animation of the film silhouette reads at roughly 0.45 width to
    height. The scaled source gave 958.7 mm on a 1,000 mm robot, a ratio of
    0.96, because it faithfully copies the hobby model rather than the screen
    proportions. Rebuild at 480 mm as four 120 mm slabs, depth unchanged.
    The width is floored by the 195 mm mini PC, not chosen freely.
    - Rebuild panels, arms and frame at a 240 mm central chassis with
    116 mm arm slabs. Verified extent 480.0 x 1000.0 x 259.9 mm.
    - Stand the GPU vertical, 130 x 300 x 60. The brief always specified a
    vertical card; the model had it flat, and 300 mm lateral no longer fits.
    - Turn the min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
    [gptars-arms.stl, gptars-frame.stl, gptars-panels.stl]
2026-08-10 Share one site menu and refresh the home page for the 480 mm body
    The menu was defined inline on all six pages and had drifted: the home
    page carried section anchors plus arrowed cross-links, while the others
    carried a plain route list, and /decals was missing from some. Define
    SITE_LINKS once in site-nav.tsx and use it everywhere, so adding a route
    updates every page. Verified identical on all six routes.
    Home page images and figures were still showing the superseded wide
    build:
    - Hero and gallery now use the current narrow-body renders instead of the
    COMPUTE V2 and ALUMINIUM V1 images.
    - The equipment-zone diagram said 958.7 mm reference; it is 480 mm.
    - The revision stamp read COMPUTE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
2026-08-10 Model the display insert that occupies the aperture
    The front panel had a 194 x 345 hole and nothing behind it. Add
    15_DISPLAY with the four bodies that actually fill it: an aperture
    doubler to restore the stiffness the hole removes from 1.2 mm sheet, a
    bonded cover lens, the bare panel module, and the driver board.
    The stack uses 22.9 mm of depth against the 25 mm reservation, so it fits
    front to back. Laterally it does not fit well: the chassis interior is
    237.6 mm and a 15.6 inch module is 223.8 mm wide, leaving 6.9 mm per side.
    That passes the panel but leaves nothing for a mounting frame, edge
    retention or a side cable exit. Recorded as a finding, with a 14 inch
    class module at roughly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
    [gptars-display.stl]
2026-08-10 Model the candidate 15.4 inch TV and reconcile the parameter file
    The listing gives 360 mm long, 28 mm thick, DC 12 V, 18 W, with HDMI in
    the interface list and two 32 mm speakers. Replace the generic bare-panel
    body and its separate driver board with a single self-contained unit,
    since panel, board, speakers and case are one 28 mm slab.
    At 28 mm the unit no longer fits in front of the mini PC: it overlapped
    the service envelope by 100 x 225 x 15.8 mm. Move the PC back against the
    rear panel and trim its service envelope from 225 to 210 mm of depth,
    which is what a 259.9 mm body can give once a real display is fitted.
    That leaves 15.5 mm between the TV and the PC envelope, and no display
    co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
    [gptars-display.stl]
2026-08-10 Add the power budget and size the battery from real duty
    Power was the binding constraint: 305 W in conversation and 600 W walking
    gave under four hours on the battery reservation, and a two-day target
    would have needed a 25 kg pack for standby alone.
    Add docs/power_budget.md with four operating modes, the reduction
    measures, runtime figures and the open decisions.
    The architecture keeps the external GPU but powers it only while
    inferring, which removes about 150 W from sleep, attentive and walking.
    The GPU is deliberately down while walking, so the two largest loads never
    peak together. Record the mechanism carefully: hard power-cycling a PCIe
    device over OCuLink is not reliable, so drive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
2026-08-10 Assess the 24 V 100 Ah candidate and record why the product class is wrong
    The 25.6 V unit fixes the voltage problem, since 8S LiFePO4 is the
    standard configuration for a 24 V bus and needs no series pairing or boost
    stage. It then fails harder on mass and volume: roughly 24 kg, which is
    the entire robot budget in one component, and about 12.5 litres against a
    5.4 litre bay. At the 23 A peak a 100 Ah pack runs at 0.23C, so the
    discharge capability is paid for in mass and never used.
    Generalise the candidate section into a comparison and name the real
    issue: deep-cycle solar, RV and camping packs are engineered for
    stationary use where mass is irrelevant and the discharge rating suits an
    inv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
2026-08-10 Move display to upper body and correct X1 Pro power path
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2026-08-10 Lock in the RTX 2000 Ada, raise the screen, repack the chassis
    Display: the aperture sat at Y 130-475, which is 13-48% of body height and
    reads as low on the chest. Raised to Y 230-575, or 23-57%, which is as
    high as it can go while staying clear of the hip axis at 610.8.
    GPU: select the RTX 2000 Ada. 16 GB, 70 W, single slot, and with no
    auxiliary power connector it runs on slot power alone, which deletes the
    separate GPU supply and the 12VHPWR cable bend problem. Chosen on VRAM per
    watt, 0.23 GB/W against 0.048 for a 250 W RTX 5070 that also offers only
    12 GB. The card keep-out falls from 130 x 300 x 60 to 90 x 200 x 50.
    Conversational draw drops from 251 W to 160 W and runtime rises fro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
    [gptars-display.stl, gptars-frame.stl, gptars-panels.stl]
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2026-08-10 Move the display into the upper body as the robot's face
    The aperture was at Y 230-575, low on the chest. design_assumptions.md
    sets an 850-950 mm interaction zone and the display as the visual face, so
    move it up to Y 655-965, which is 66-96% of body height with the screen
    centred at 810 mm.
    Two changes were needed to make it fit.
    The front face is now two panels either side of the hip break rather than
    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
    [gptars-display.stl, gptars-panels.stl]
2026-08-11 Draw the hip drive train around the selected AK45-10
    Selected: two CubeMars AK45-10 V3.0 at the hips, one Rubik Link V3.0 CAN
    hub, and the power/CAN harness.
    Published AK45-10 figures are 2.5 N.m rated, 7 N.m peak, 10:1 internal,
    53 dia x 43, 260 g, 24 V nominal. Against a 60 N.m hip requirement the
    actuator alone is 24 times short, so the joint is built as a two-stage
    train: the AK45-10 drives an external 24:1 stage, giving 60 N.m continuous
    and 168 N.m peak, or 51 and 143 after an assumed 85% efficiency. Total
    ratio 240:1. The peak covers the 80-180 N.m landing band the power budget
    derived.
    The second stage is specified as cycloidal or two-stage planetary rather
    than harmonic, deliberat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
    [gptars-drive.stl]
2026-08-11 Rebuild the cage around a proper hip bulkhead
    The frame was a naive rectangular box of extrusions and the bearing
    carriers interpenetrated the rails. Rebuild it the way the interference
    report already prescribed: a machined transverse joint bulkhead carrying
    the bearings and the reduction mounting face, with the rails terminating
    into it.
    - Rails split into lower, 30 to 570, and upper, 652 to 950, per corner.
    - A machined 20 x 82 x 170 bulkhead block per side occupies the 570 to 652
    band, replacing both rails locally, tying front to rear, and carrying
    the 20 mm bearing bore on the hip axis.
    - Crossmembers and depth members regrouped onto the equipment levels at
    30, 205, 480, 660 and 9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
    [gptars-drive.stl, gptars-frame.stl, gptars-joints.stl]
2026-08-11 Archive the current CAD state to a local F3D
    Fusion's free tier limits editable cloud documents, so the design could
    not be saved. An F3D archive export writes to local disk and does not
    consume a document slot, so today's geometry is captured regardless:
    the narrowed 480 mm body, the hip bulkhead cage, the AK45-10 drive train,
    the display insert and the harness routing.
    Committed so the work also exists off this machine.
    [GP_TARS_V2_1000_NARROW480_CAGE_V1.f3d]
2026-08-11 Adopt a two-joint compass gait and record its geometry
    Two hip actuators is the selected configuration. Record it as a compass
    walker rather than treating it as a reduced version of a four-joint
    machine: two rigid limbs on a shared hip axis, swinging in the sagittal
    plane, which is the classic passive-dynamic form and is closer to the
    screen robot's slab pivoting than the knee inferred earlier from replica
    footage.
    Step geometry at a 610.845 mm leg: 20 degrees of splay gives a 418 mm
    step in 1.75 s. Speed is independent of splay angle, because step length
    and swing time both scale with it, so walking speed is set purely by joint
    angular velocity. At 0.4 rad/s that is 0.24 m/s, and the 12.8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
2026-08-11 Rebuild the assembly from a committed script and consolidate to one file
    The archive exported earlier held the wrong document. Inside the Fusion
    bridge the bound `root` pointed at the design being edited while
    `app.activeDocument` pointed elsewhere; STL exports passed a component
    from `root` and were correct, but the archive export takes no component
    and captured the active document instead. Verifying that archive as a
    valid zip proved only that it was not corrupt, not that it was the right
    model, and the solid model was lost when the session document closed.
    The meshes and cad/parameters.py both survived, so the design was fully
    recoverable. Add cad/build_model.py, which regenerates the en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
    [GP_TARS_V2_1000_ALUMINIUM_COMPUTE_V2.f3d, GP_TARS_V2_1000_ALUMINIUM_CONCEPT_V1.f3d, GP_TARS_V2_1000_CONCEPT_V0.f3d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]
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2026-08-11 Model the feet as real parts and colour-code the CAD
    The rocker was a curve cut into the bottom of the hollow arm shell, which
    left an open curved edge and no foot at all. The limbs now stop at 80 mm
    and a separate 16_FEET component carries a formed shoe and a replaceable
    elastomer contact pad per side.
    Modelled solid, each shoe came out at 1,758 cm3, or 4.75 kg a side, which
    is billet rather than a fabricated part. Hollowed to 3 mm plate it is
    199 cm3 and the whole component is 2.14 kg including both pads.
    The pad is the outer 6 mm of the 200 mm rocker, sitting from ground level
    to 55.9 mm up the curve, so it wears and is replaced without touching the
    structural shoe.
    Structure is now 16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
    [gptars-arms.stl, gptars-feet.stl]
2026-08-11 Add the charge and support dock
    The dock is a cradle the robot is placed into, not a station it returns
    to. Two hip joints give forward walking in one plane with no turning or
    reversing, so autonomous docking is not achievable and the design should
    not pretend otherwise.
    That constraint lets the structure do three jobs at once: charge the
    pack, support the robot during motion testing as the fall-arrest fixture
    the specification requires, and supply the GPU from mains rather than the
    battery while docked.
    Modelled as 17_DOCK: base plate, backboard, port and starboard funnel
    guides to centre the rockered feet, a contact block, and a gantry with
    uprights and crossbar for the fall-arrest tethe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
    [GP_TARS_V2_R04.f3d, GP_TARS_V2_R05.f3d, gptars-dock.stl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]
2026-08-11 Write the dock up on the site
    The dock existed in the model and the viewer but nowhere in the written
    record, so the site still described charging as a single sentence about a
    future recharge path.
    Replace that with the actual design in docs/power_budget.md: the render of
    the robot seated in the cradle, the three roles the structure serves, the
    geometry as modelled, and the contact height at Y=470 with the note on why
    Y=300 was abandoned.
    Record the two requirements that are not optional. Contacts must be blade
    or brush, since spring pins will not carry 30 A. And a detect pin must
    close the contactor only when the robot is seated, because 12.8 V at 30 A
    across exposed terminals is a fire r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
2026-08-11 Raise the second stage to 32:1 and boost the actuator rail to 24 V
    Holding a 20 degree splay at 33 kg needs 53.3 N.m, and 24:1 delivered
    51.0 after gearbox efficiency. That was break-even, so the drive is
    changed on two fronts that together give both more torque and more speed
    than before.
    Second stage goes 24:1 to 32:1, so 320:1 total. Continuous rises from 51
    to 68 N.m, a 28 per cent margin rather than a 4 per cent shortfall, and
    peak from 143 to 190. A cycloidal drive changes ratio by lobe and pin
    count rather than size, so this is the same envelope and the 90 x 200 x 50
    reservation is unchanged.
    Actuators move onto a 24 V rail fed by a boost stage from the 12.8 V bus.
    The AK45-10 is 24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
    [GP_TARS_V2_R05.f3d, GP_TARS_V2_R06.f3d]
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2026-08-11 Redraw the general arrangement with dimensions
    The elevation drawing was two revisions stale: it showed the 958.7 mm
    scaled-source width, a 532 mm chassis and the display in the Upper Lid,
    none of which describe the robot any more.
    Redraw it as a dimensioned general arrangement, front and side elevation
    side by side, against the current 480 x 1000 x 259.9 build.
    Dimensioned: overall height and width, 240 chassis, 116 leg-arm slabs
    with the 4 mm running clearance called out, hip axis at 610.8, foot at 80,
    display aperture 174 x 310 with its 35 mm to the crown, and 259.9 depth on
    the side view. The side elevation also carries the display stack depth and
    the 200 mm rocker with its 12.1 mm cle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
2026-08-12 Correct the rocker foot: wrong formula, wrong plane, unstable radius
    Three errors, found because the drawn feet looked too round.
    The clearance formula was inverted. It is (L - R)(1 - cos theta), where L
    is the 610.845 mm hip height, not R(1 - cos theta). A larger radius raises
    the arc centre and shortens the effective pendulum, so it gives less
    clearance, not more. Real clearance at the old R=200 and 20 degrees was
    24.8 mm, not the 12.1 mm recorded.
    The radius was also too small to stand on. A body rocking on a curved
    sole is stable only while its centre of mass sits below the centre of
    curvature. The estimated centre of mass is 381 mm and the arc centre was
    at 200, so the robot would tip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
    [GP_TARS_V2_R07.f3d, GP_TARS_V2_R08.f3d, gptars-feet.stl]
2026-08-12 Lift the chassis clear of the floor so the feet carry the robot
    The feet looked wrong because there was nothing for them to do. The
    central chassis ran the whole way to Y=0, so the body sat on the floor
    with slabs beside it and the legs carried no load. A foot cannot read
    correctly on a machine that is resting on its body.
    Apply the ground clearance the specification has always called for and
    parameters.py has always held unused. The chassis underside now sits at
    25 mm, inside the 10 to 25 mm band, and only 16_FEET reaches Y=0.
    Twenty-five is not arbitrary. The body hangs from the hips, and at the
    20 degree working splay the hip drops 12.7 mm as the sole rolls, so the
    underside has to clea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
    [GP_TARS_V2_R08.f3d, GP_TARS_V2_R09.f3d, gptars-panels.stl]
2026-08-12 Show the decals on the robot, and correct the wordmark
    The sheet carried the artwork but nothing showed where any of it goes.
    Add a placement drawing: front and rear elevations with each decal drawn
    in position, and put it on the homepage gallery, the decals page and the
    architecture document.
    Front carries the wordmark, the starts-without-warning and crush
    triangles, pinch stripes across the hip gap and down the limb leading
    edges, and the panel index marks. Rear carries the E-stop surround at
    Y 700, the isolate warning, the three service labels on their own access
    panels, the data plate, and the live and hot-surface triangles beside the
    hazards they refer to.
    Correct the wordmark against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
2026-08-12 Reconcile documentation with the 12.8 V bus architecture
    The parametric master-variable block still declared BATTERY_VOLTAGE = 24 V and
    the software stack still described the mini-PC PD source as fed from 24 V. Both
    predate the decision to distribute at 12.8 V LiFePO4 and boost to 24 V per
    actuator. parameters.py was already correct; the prose was not.
    The actuator envelope now states 24 V at the actuator from a step-up stage,
    which keeps the 24-48 V actuator market open without running the robot at that
    voltage.
2026-08-12 Put the decals on TARS on the front page
    The hero was a flat-grey Fusion screenshot whose front face was foreshortened
    hard enough that a decal applied to it would have read as a sliver. Replaced it
    with cad/render_hero.py, which projects a three-quarter view with its own
    perspective camera and places every decal at the millimetre position in the
    decal schedule: rotated orange wordmark and dot matrix below the display,
    pinch stripes on the hip gap and limb leading edges, crush and
    starts-without-warning triangles, panel index marks and the side build stamp.
    Geometry and the bus voltage on the stamp come from parameters.py, so the hero
    regenerates with the model rather than drifting from it.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
2026-08-12 Add camera, microphones and ranging to the CAD; fix a broken hero download
    Sensors. 10_SENSORS held only an IMU keep-out while the specification has listed
    a camera, depth camera, microphone array, ToF and ground-contact sensors from
    the start. Added eight bodies using the hardware already selected on main: the
    OAK-D Pro W USB and the ReSpeaker XVF3800, plus their shared cassette plate, a
    ToF pair, a LiDAR mount pad and a contact sensor inside each shoe. The panels
    they see and listen through are cut to match.
    The cassette as specified does not fit, and the arithmetic is worth recording.
    Camera 45 plus its 10 mm top margin, display module 328 and microphone 35 need
    418 mm of upper front fac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
    [GP_TARS_V2_R10.f3d, gptars-display.stl, gptars-panels.stl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]
2026-08-12 Record GPTars_v4 as the live Fusion document
    The model is now saved in Fusion as GPTars_v4: 90 bodies, 480 x 1000 x 259.9,
    the same build exported to cad/output/GP_TARS_V2_R10.f3d. Verified against the
    saved document rather than assumed, including the camera at 945-990 and the
    display module at 616-944.
    Naming it in parameters.py, the builder docstring, the interference report and
    the site matters more here than it looks. An F3D archive export takes the ACTIVE
    document, and a previous model was lost by assuming the right one was active.
    Recording the expected name, body count and extent gives the next session
    something to check against before it edits or exports anything.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
2026-08-12 Audit the new model against every earlier archive
    Reopened all eleven historical F3D archives from git history and compared their
    bodies by name against GPTars_v4. The current model is a strict superset of R06
    through R09: every body name in those exists in it, plus the eight new sensor
    bodies.
    Everything the older archives appear to be missing turns out to be a rename or a
    recorded decision. The 24:1 reductions became 32:1 when the ratio was raised.
    FRAME_VERTICAL/CROSS/DEPTH became RAIL/CROSS/DEPTH, and the frame now carries 28
    members against 22, modelled as hollow section. MINI_PC_KEEP_OUT became the
    selected MINISFORUM envelope. ACTUATOR_MAIN_LOWER became ACTUATOR_HIP_AK45_10.
    One gen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
